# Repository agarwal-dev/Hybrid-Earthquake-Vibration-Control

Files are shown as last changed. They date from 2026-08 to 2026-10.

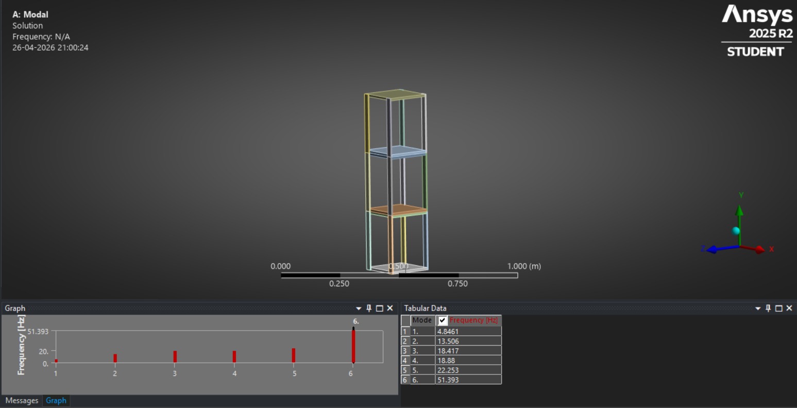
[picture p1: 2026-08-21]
Modes on Ansys.jpeg

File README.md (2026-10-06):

# Hybrid Earthquake Vibration Control for Buildings

Design and experimental validation of a **hybrid active–passive vibration control system** for a 3-storey building model, developed as a Design Lab (ME-306) project.

## Project Overview

A ~3 ft acrylic and MDF scale model was designed to study structural vibrations under simulated seismic excitation. The system combines **spring-based passive isolation** with **PID-controlled active damping** to reduce structural vibrations.

## Key Features

- 3-storey acrylic building model (~0.9 m, ~1.2 kg)
- Four spring-based base isolators
- ANSYS modal and harmonic-response analysis
- Arduino Mega-based PID controller
- MPU6050 accelerometer for real-time vibration feedback
- High-torque servo for active counter-torque
- Hybrid passive + active vibration control

## System Architecture

**Seismic Excitation → Spring Isolators → Building → MPU6050 → Arduino Mega (PID) → Servo → Counter-torque**

Passive isolation attenuates the primary ground excitation, while the active control system suppresses residual vibrations through real-time feedback.

## Analysis

Modal analysis was performed in **ANSYS 2025 R2**.

| Mode | Frequency |
|---|---|
| 1st lateral bending | 4.846 Hz |
| 2nd lateral bending | 13.506 Hz |
| Torsional | 18.417 Hz |
| Higher lateral | 18.88 Hz |

The first two modes were identified as the critical design frequencies for vibration control.

Harmonic response analysis was also performed to study the structural response under excitation.

## Control System

The active damping system uses:

- **Arduino Mega 2560** – PID control and servo actuation
- **MPU6050** – 6-DOF accelerometer/gyroscope for vibration feedback
- **High-torque servo** – generates counter-torque to suppress vibration

The PID controller uses acceleration error as feedback to determine the required actuator response.

## Experimental Setup

The physical system consists of:

- 16 acrylic columns
- 6 MDF floor slabs
- MDF base plate
- 4 coil springs
- Arduino Mega
- MPU6050
- High-torque servo
- Separate power supply for the servo

## Tools Used

- ANSYS 2025 R2
- Arduino
- MPU6050
- PID Control

Modes on Ansys

https://github.com/user-attachments/assets/708dc5bd-00dd-447a-ac16-04566eecffb7

## Project Status

**Completed**

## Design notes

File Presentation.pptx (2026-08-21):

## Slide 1

Design Lab Project (ME-306)

Hybrid Earthquake Vibration Control for Buildings

Group Members - Tuesday Group D
Bewele Suyog Asaram (2023MEB1337)
Daggolu Sai Mohith Reddy (2023MEB1338)
Deepanshi Dhir (2023MEB1339)
Dev Agarwal (2023MEB1340)
Diya Seal (2023MEB1341)

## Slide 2

Problem Statement

Introduction

- Earthquakes generate dynamic lateral forces in structures
- These forces cause vibrations, instability, and possible failure
- Traditional buildings rely only on structural strength
- Modern approach: Control vibrations instead of resisting them

Problem Statement

- Excessive vibrations during earthquakes lead to:
  - Structural damage
  - Resonance effects
  - Reduced safety
- Passive systems alone are not adaptive
- Active systems alone depend on power
Therefore, need for a hybrid vibration control system

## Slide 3

Project Objectives

1. Structural Modeling: Design and fabricate a 3-storey acrylic and WPC building scale model (~3 ft, 1.2 kg) representative of low-rise structures.

2. Numerical Simulation: Perform Modal and Harmonic Response analyses in ANSYS 2025 R2 to extract natural frequencies and mode shapes.

3. Passive Damping: Implement spring-based passive isolation at the base to reduce incoming ground excitation energy.

4. Active Control: Design a PID-based active damping controller using a high-torque servo motor driven by Arduino Mega with MPU6050 feedback.

5. System Validation: Experimentally verify hybrid system performance under simulated seismic excitation and compare with baseline.

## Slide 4

Working Principle

Active Damping and Passive Damping

Passive damping in our system is achieved using a spring mechanism. This works on the principle of a tuned damper.
When the structure vibrates, the attached spring begins to shear. This oscillation absorbs a portion of the vibrational energy from the structure. As a result, the vibration amplitude decreases over time. The main advantage of this system is that it does not require any external power.
Active damping in our system is implemented using a servo motor. The servo motor is controlled by an Arduino, enabling precise, controlled movement. When vibrations occur, the motor generates motion in the opposite direction.
This opposing motion helps counteract vibrations and stabilise the structure more quickly. Unlike passive damping, active damping can adapt to changing conditions. However, it requires a continuous power supply and control mechanisms.

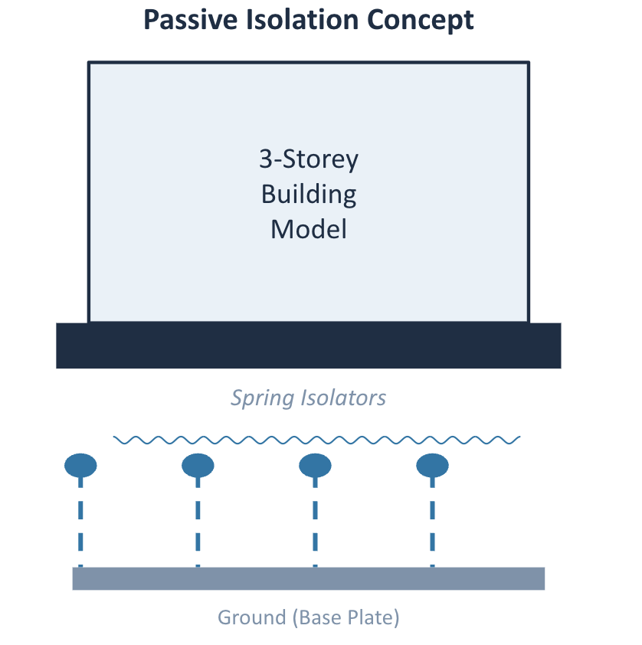
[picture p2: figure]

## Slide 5

System Architecture

Hybrid Vibration Control — Signal Flow

Seismic
Excitation

Passive Damping
(Spring Isolators)

3-Storey
Building Model

MPU6050
Accelerometer

Arduino Mega
(PID Controller)

← Feedback loop

Active Damping — High-Torque Servo
generates counter-torque to suppress vibration

Outcomes: Passive damping attenuates primary seismic energy · Active PID controller suppresses residual vibrations · Real-time feedback via MPU6050

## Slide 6

Governing Equations

Equation of Motion (Single Degree of Freedom):

mẍ + cẋ + kx = F(t)

PID Control Law:

u(t) = Kp·e(t) + Ki·∫e(t)dt + Kd·de/dt

m — Mass of the structure

c — Damping coefficient

k — Stiffness of the structure

x, ẋ, ẍ — Displacement, velocity, and acceleration

F(t) — External seismic force (time-varying)

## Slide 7

Modal Analysis Natural Frequencies

ANSYS 2025 R2 3-Storey Acrylic Model

Mode

Frequency (Hz)

Mode Shape

Significance

1

4.846

1st lateral bending

Primary seismic risk — design target

2

13.506

2nd lateral bending

Secondary target

Critical design frequencies: Mode 1 (4.846 Hz) and Mode 2 (13.506 Hz). Passive and active systems tuned to suppress these modes.

3

18.417

Torsional

4

18.88

Higher lateral

5

22.253

Combined

6

51.393

High-freq. axial

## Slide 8

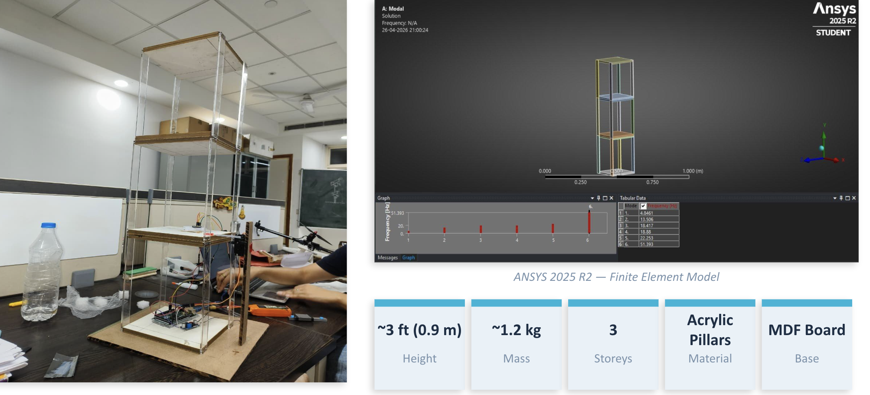
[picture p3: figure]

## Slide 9

Natural Frequencies : Modal Analysis

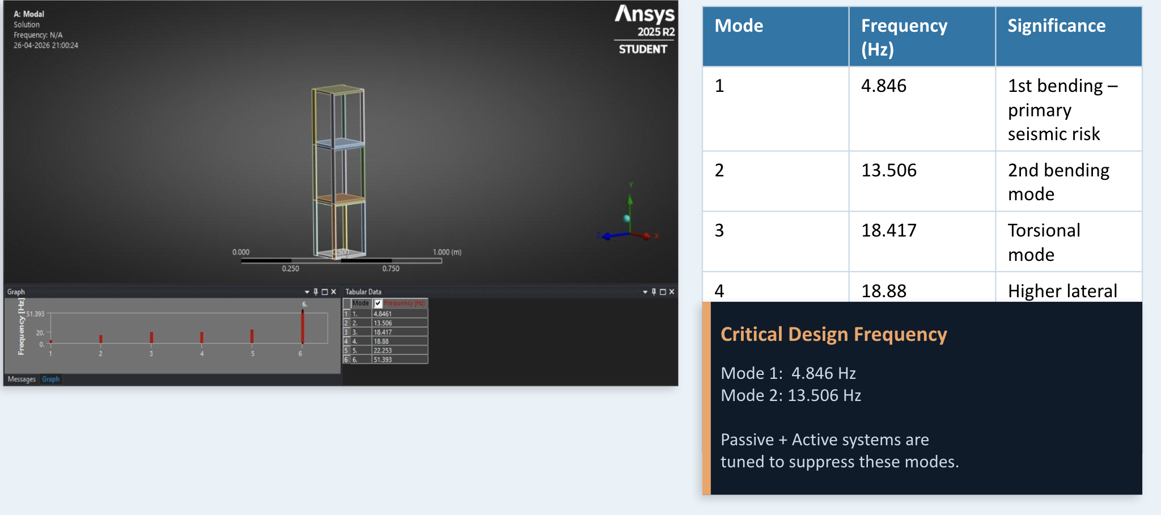
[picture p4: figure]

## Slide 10

Harmonic Response Analysis

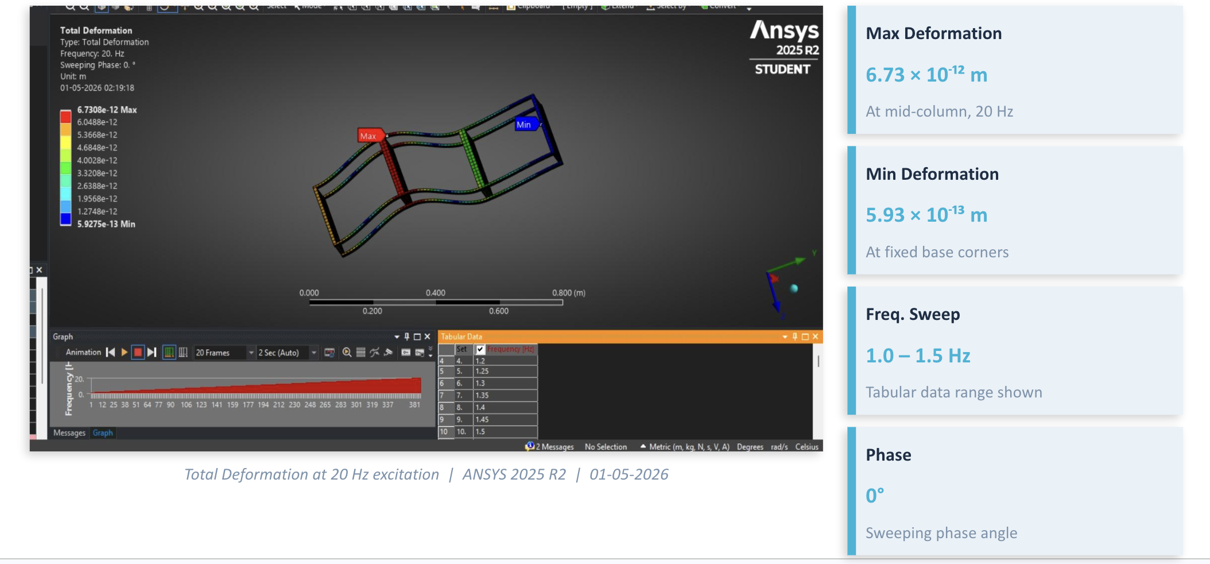
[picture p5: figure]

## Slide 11

Passive Damping System

Spring-Based Base Isolation

What is Passive Damping?
Passive damping uses mechanical elements, such as springs, rubber pads, or friction dampers, placed between the building foundation and the ground. They absorb and dissipate seismic energy without requiring any external power or control signal.
Our Implementation
Springs are installed at the four base corners of the acrylic building model. When the shake table excites the structure, the springs decouple ground motion from the building frame, significantly reducing the energy transmitted to the floors.
Limitation
Passive systems are designed for a fixed frequency range. At excitation frequencies near natural modes (4.846 Hz, 13.5 Hz), residual vibration persists, which is why active control is also employed.

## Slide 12

Active Damping System

Arduino Mega + MPU6050 + High-Torque Servo

Arduino Mega 2560: Main microcontroller (16 MHz, 54 I/O pins). Reads accelerometer data via I²C and outputs PWM signal to servo. Runs real-time PID loop at ~100 Hz.

MPU6050 Accelerometer / Gyro: 6-DOF sensor, 16-bit resolution, ±16g range. Measures storey acceleration in real time via I²C. Provides error feedback for the PID controller.

High-Torque Servo Motor: Active actuator physically attached to the building frame column. Generates controlled counter-torque proportional to the PID output to suppress residual vibrations.

Control Loop: MPU6050 senses vibration → Arduino reads acceleration → PID computes error & output → Servo generates counter-torque → Vibration suppressed

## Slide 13

PID Controller — Design & Tuning

Control Law:

u(t) = Kp · e(t) + Ki · ∫e(t) dt + Kd · de(t)/dt

Kp — Proportional Gain: Directly proportional response to current acceleration error. Controls how aggressively the servo reacts to present vibration.

Ki — Integral Gain: Accumulates past error over time. Eliminates steady-state offset and drift in the accelerometer reading.

Kd — Derivative Gain: Reacts to rate of change of error. Provides predictive damping, preventing overshoot and improving settling time.

e(t) — Error Signal: Difference between desired acceleration (setpoint = 0 m/s²) and measured acceleration from MPU6050.

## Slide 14

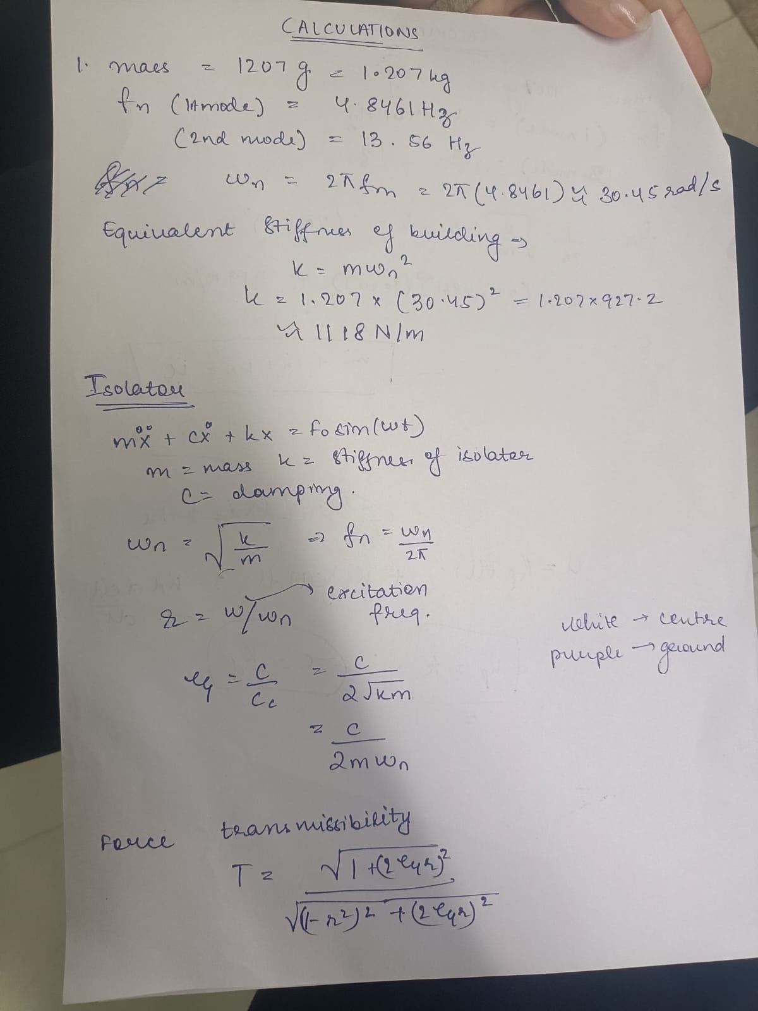
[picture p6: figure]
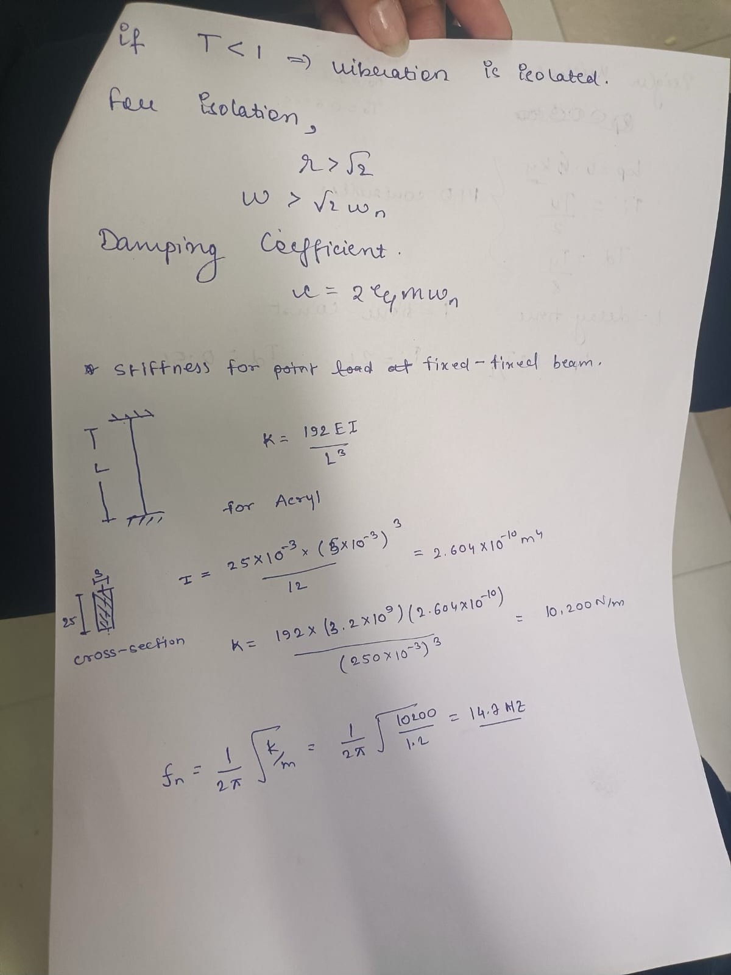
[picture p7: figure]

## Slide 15

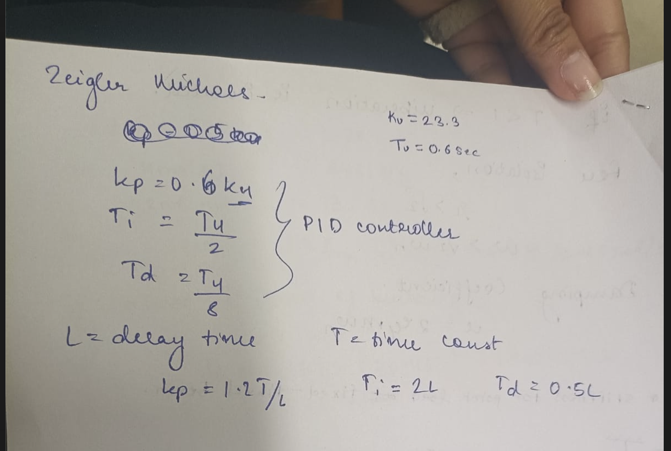
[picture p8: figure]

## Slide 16

Experimental Setup & Hardware

1. Acrylic Columns (×16)
Vertical load-bearing members, transparent, lightweight

2. MDF Floor Slabs (×6)
Simulates floor mass; 3 storeys at equal spacing

5. Arduino Mega
Main controller; runs PID loop and servo PWM output

6. MPU6050 Accelerometer
Mounted on 2nd floor; I²C interface, 6-axis sensing

3. Base Plate (MDF)
Houses Arduino Mega and provides mounting for springs

7. High-Torque Servo
Active actuator; attached to frame column; counter-torque

4. Coil Springs (×4)
Passive isolation at base corners; tuned for stiffness

8. Power Supply
USB 5V for Arduino; separate 5V/2A rail for servo

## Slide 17

Conclusion & Future Work

Key Conclusions

• 3-storey acrylic scale model designed, fabricated, and simulated in ANSYS 2025 R2. Natural frequencies validated: 4.846 Hz (Mode 1), 13.506 Hz (Mode 2).

• Harmonic response confirmed maximum deformation near resonance; results informed passive spring selection.

• Spring-based passive isolation.

• Full hybrid system (Arduino + MPU6050 + Servo, PID-controlled).

• PID gains (Kp, Ki, Kd) tuned iteratively to minimise overshoot and achieve acceptable settling time.

Future Work

• Multi-directional Control — extend to 2-axis servo actuation for simultaneous X and Y lateral excitations.

• Adaptive / ML-based Control — replace fixed-gain PID with a reinforcement-learning controller that self-tunes in real time.

• Shake Table Validation — test with recorded seismic waveforms (El Centro, Bhuj) on a calibrated shake table.

• Full-Scale Feasibility — investigate hydraulic or electromagnetic actuators for real-structure implementation.

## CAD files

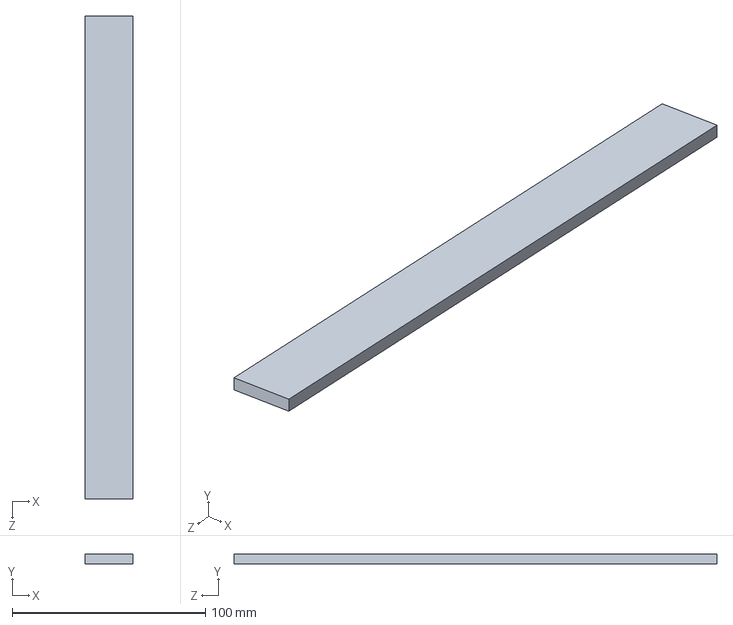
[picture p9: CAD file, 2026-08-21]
Pillar (1).SLDPRT
25.0 x 5.00 x 250.0 mm

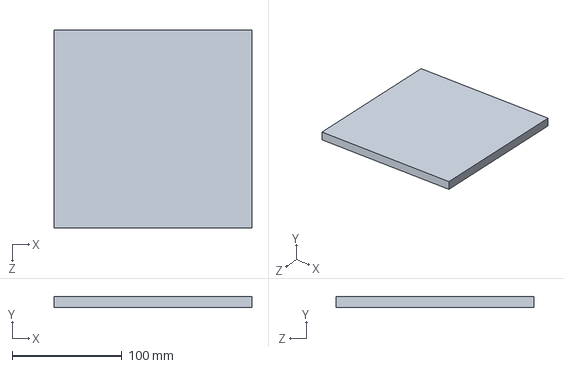
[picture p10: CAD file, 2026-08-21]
Floor plate (1).SLDPRT
180.0 x 10.0 x 180.0 mm
